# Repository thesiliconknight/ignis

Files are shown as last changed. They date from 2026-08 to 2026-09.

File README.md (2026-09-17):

# Ignis
A low-voltage controller board for driving a 220V 400W aluminum PTC heater via an external SSR, it has a NTC for temperature readings, an OLED status/info display, and MOSFET-isolated relay stuff. The board uses the CH32V006F8P6 MCU, its mainly used for triggering the SSR and reading temps,it keeps all mains voltage completely off of the board.
## Pictures
| Top View | Bottom View |
| :---: | :---: |
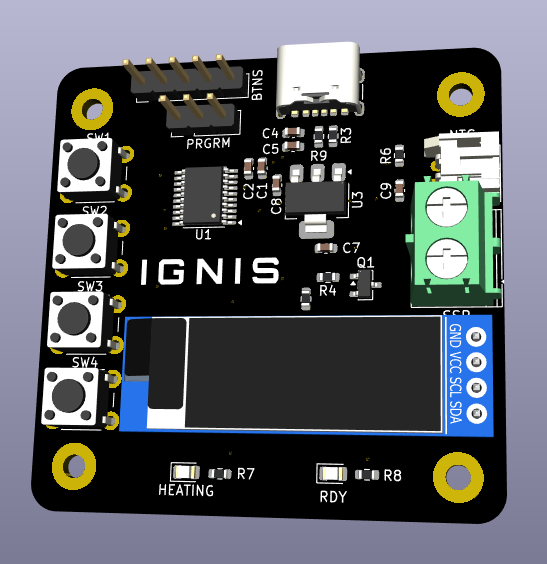
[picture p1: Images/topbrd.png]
Board Front
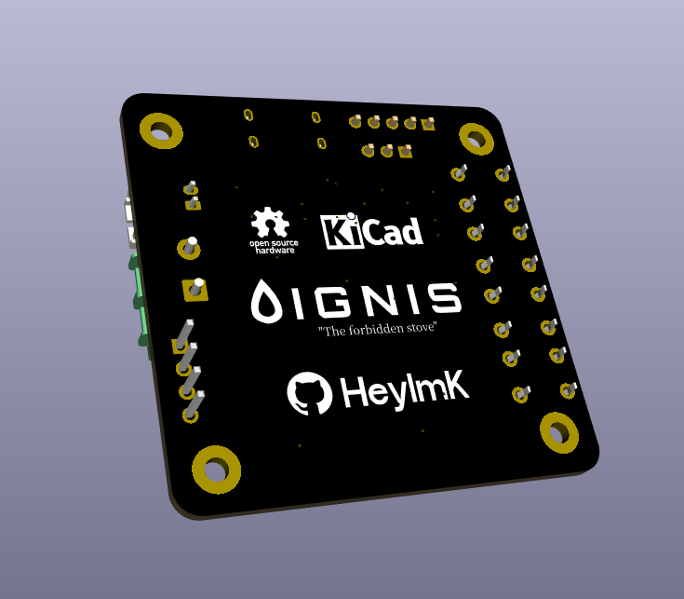
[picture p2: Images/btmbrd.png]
Board Back
|  |  |
## Features
* **Main Controller:** CH32V006F8P6,62KB Flash and 8KB RAM.
* **USB-C Power:** Board is powered over USB-C.
* **No High Voltage:** The PCB handles 5V/3.3V logic. The 220V AC mains load is kept off-board and switched safely via a external SSR.
* **Precision Sensing:** It uses a 100K NTC thermistor it can read up to 300°C.
* **OLED Interface:** I2C header for a 0.91" SSD1306 OLED displaying target temps, current temp, and heating status.
* **Status LEDs:** Inbuilt HEATING and RDY LEDs gives the heater state without needing a screen.
* **Button Header:** 5-pin header breaking out 4 tactile buttons for menu navigation.
## Components Used
* **Microcontroller:** WCH CH32V006F8P6 (TSSOP-20)
* **Power Input:** USB-C receptacle (power-only)
* **High Voltage Switch:** External SSR connected via terminal block
* **Heater:** 220V 400W PTC Aluminum Heating Plate
* **Thermistor:** 100K NTC connected via a JST-PH 2-pin connector
* **Screen:** 0.91" SSD1306 I2C OLED Module
* **Miscellaneous:** AMS1117-3.3V Regulator, AO3400A MOSFET, 4x tactile buttons, 2x status LEDs, and assorted 0603 passives.

## Bill of Materials (BOM)

| Qty | Component | Footprint | Designator(s) | Purchase Link | Price (Rs) |
| :---: | :--- | :--- | :--- | :--- | :--- |
| 1 | Conn_01x05_Socket (Buttons Header) | PinHeader_1x05_P2.54mm_Vertical | BTNS | N/A (any 2.54) | 0 (Already have) |
| 5 | 100nF Capacitor | C_0603_1608Metric | C1, C7, C8, C9, C4| [Link](https://www.google.com/aclk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) | 0 (Already have) |
| 1 | 1µF Capacitor | C_0603_1608Metric | C2 | [Link](https://robu.in/product/1uf-1000nf-50v-capacitor-0603-smd-package-pack-of-20/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) | 11.00 |
| 1 | 10µF Capacitor | C_0603_1608Metric | C5 | [Link](https://robu.in/product/cl10a106ma8nrnc-samsang-25v-10uf-x5r-%C2%B120-0603-multilayer-ceramic-capacitors-mlcc-smd-smt-rohs/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) | 20.00 |
| 2 | LED (Heating / Ready) | LED_0805_2012Metric | HEATING, RDY | N/A (any 0805) | 0 (Already have) |
| 1 | USB-C Receptacle (Power Only) | USB4125-xx-x 6P TopMnt Horizontal | J6 | [Link](https://www.ktron.in/product/6-pin-usb-type-c-connector-smd/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) | 15.00 |
| 1 | Conn_01x02_Socket (NTC) | JST_PH_S2B-PH-K_1x02_P2.00mm_Horizontal | NTC | [Link](https://robu.in/product/ph-aw-2mm-2-pin-wafer-male-connector-through-hole-right-angle/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) | 0 (Already have) |
| 1 | JST-PH 2.0 Female Connector | N/A (Off-board wire harness) | — | [Link](https://hubtronics.in/1508?srsltid=AU7gw4Wmjln1E9tSbj1yLX3e6CGLNVZjP4-da3Qo7EFz9MvRA4VvwUHm) | 5.00 |
| 1 | Conn_01x03_Pin (Programming Header) | PinHeader_1x03_P2.54mm_Vertical | PRGRM | N/A (any 2.54) | 0 (Already have) |
| 1 | AO3400A N-Channel MOSFET | SOT-23 | Q1 | [Link](https://robu.in/product/ao3400-xblw-30v-5-8a-34m%cf%894-5v5a-1-4w-700mv250ua-1-n-channel-sot-23-3l-mosfets-rohs/) | 18.00 |
| 2 | 5.1kΩ Resistor | R_0603_1608Metric | R3, R9 | [Link](https://www.etstore.in/products/g7551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) | 0 (Already have) |
| 1 | 1kΩ Resistor | R_0603_1608Metric | R4 | [Link](https://robu.in/product/1k-ohm-1-4w-0603-surface-mount-chip-resistor-pack-of-100/) | 10.15 |
| 1 | 10kΩ Resistor | R_0603_1608Metric | R5 | [Link](https://robu.in/product/10k-ohm-1-4w-0603-surface-mount-chip-resistor-pack-of-100/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) | 13.00 |
| 1 | 100kΩ Resistor | R_0603_1608Metric | R6 | [Link](https://robu.in/product/100k-ohm-1-4w-0603-surface-mount-chip-resistor-pack-of-100/) | 11.10 |
| 2 | 330Ω Resistor | R_0603_1608Metric | R7, R8 | [Link](https://robu.in/product/rc0603jr-07330rl-yageo-res-thick-film-0603-330-ohm-5-0-1w1-10w-%C2%B1100ppm-c-pad-smd-t-r/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) | 0 (Already have) |
| 1 | 0.91" I2C OLED | Untitled | SCREEN | [Link](https://www.ktron.in/product/0-91-inch-white-color-oled-display-i2c/) | 180.00 |
| 1 | Conn_01x02_Socket (SSR) | TerminalBlock_Phoenix_PT-1,5-2-5.0-H_1x02_P5.00mm_Horizontal | SSR | [Link](https://evelta.com/2-pin-screw-connectors-pcb/?sku=083-Prime-500-2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) | 18.00 |
| 4 | SW_Push (6mm Tactile) | SW_PUSH_6mm | SW1, SW2, SW3, SW4 | [Link](https://robu.in/product/tsd001b06035a03-bzcn-6mm-6mm-50ma-round-button-direct-insert-6mm-350gf-12v-plugin-tactile-switches-rohs/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) | 8.00 |
| 1 | CH32V006FxPx MCU | TSSOP-20_4.4x6.5mm_P0.65mm | U1 | [Link](https://www.etstore.in/products/a2668?_pos=1&_psq=ch32v006&_psid=08be7c9a0&_ss=e) | 40.00 |
| 1 | AMS1117-3.3 LDO | SOT-223-3_TabPin2 | U3 | [Link](https://robu.in/product/ams1117-3-3v-1a-sot-223-voltage-regulator-ic-pack-of-5-ics/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) | 18.00 |
| 1 | 220V 400W PTC Aluminum Heater Plate | N/A (Off-board) | — | [Link](https://hubtronics.in/aluminum-ptc-heating-plate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) | 500.00 |
| 1 | SSR-40 DA Solid State Relay | N/A (Off-board) | — | [Link](https://robu.in/product/dc-ac-ssr-40da-solid-state-relay-module-3-32vdc24-380vac-40a/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) | 269.00 |
| 1 | 100K NTC 3950 Thermistor | N/A (Off-board) | — | [Link](https://robu.in/product/thermistor-100k-ntc-1-meter-cable-temperature-sensor/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) | 42.00 |
| | | | | **Component Total:** | **1178.25 Rs** (12.30$)|

*Note: Shipping and delivery fees across various vendors will add an estimated 100 - 200 Rs to the final cost.*

| Schematic Design |
| :---: |
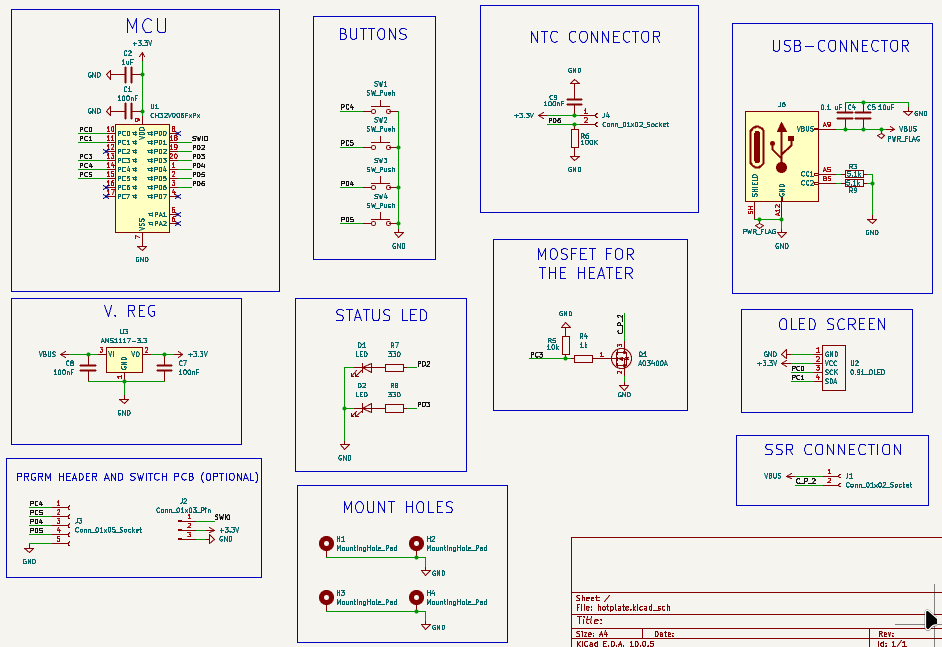
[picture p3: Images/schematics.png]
Schematic Diagram
|  |

| PCB Top Layer Routing | PCB Bottom Layer Routing |
| :---: | :---: |
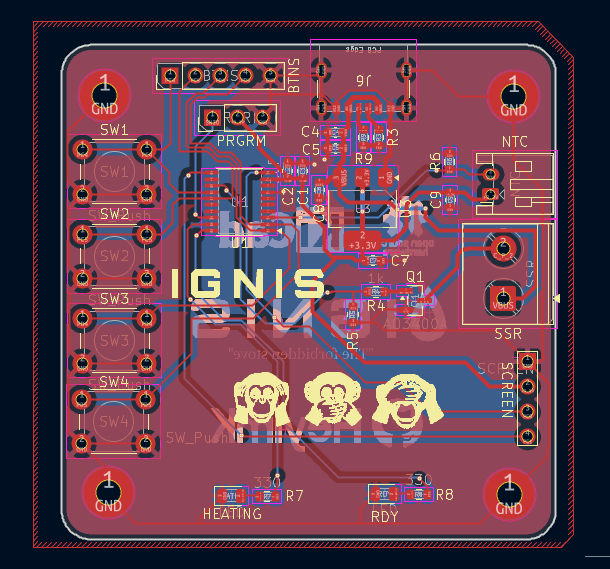
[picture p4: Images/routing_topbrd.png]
Top Routing
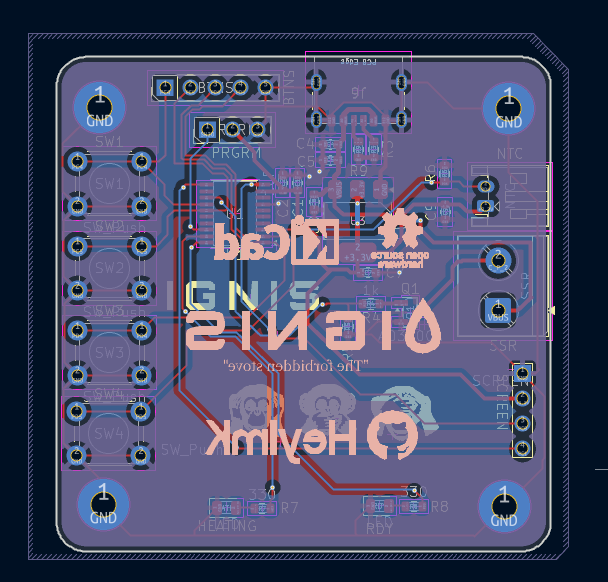
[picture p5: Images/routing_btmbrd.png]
Bottom Routing
|  |  |
### Connections
* **Power (USB-C to 3.3V):** 5V via USB-C (J6) and routes to the SSR connector and the AMS1117 V.REG (U3), which powers the MCU, OLED, and thermistor etc.
* **Thermistor Input (NTC):** Connects the 100K NTC between 3.3V and the MCU's ADC pin (PD2).
* **SSR Driver (SSR):** The MCU's PWM pin (PC3) switches the AO3400 Gate (Q1). The MOSFET pulls the negative side of the SSR terminal to GND, triggering the external relay.
* **OLED Header (SCREEN):** Connected to PC1 (SDA) and PC2 (SCK).
* **Button Header (BTNS):** 5-pin header breaking out the 4 tactile switches (SW1–SW4).
* **Programming Header (PRGRM):** Breaks out 3.3V, GND, and the single-wire debug line (PD1 / SWIO) for the programmer.
* **Status LEDs:** HEATING and RDY LEDs (Pin PD2 & PD3)
## License
This hardware project is open-source and licensed under the CERN Open Hardware Licence Version 2 - Strongly Reciprocal (CERN-OHL-S-2.0). 
You are free to copy, modify, distribute, and manufacture this board for personal or commercial use. However, if you modify these schematic or layout files and distribute your new design, you must release those modifications under this exact same CERN-OHL-S-2.0 license.
This design is shared without any warranty or implied guarantee. Check the LICENSE file for the full legal text.

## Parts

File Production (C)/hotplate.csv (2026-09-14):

Id | Designator | Footprint | Quantity | Designation | Supplier and ref
1 | BTNS | PinHeader_1x05_P2.54mm_Vertical | 1 | Conn_01x05_Socket
2 | C1, C7, C8, C9 | C_0603_1608Metric | 4 | 100nF
3 | C2 | C_0603_1608Metric | 1 | 1uF
4 | C4 | C_0603_1608Metric | 1 | 0.1 uF
5 | C5 | C_0603_1608Metric | 1 | 10uF
6 | HEATING, RDY | LED_0805_2012Metric | 2 | LED
7 | J6 | USB_C_Receptacle_GCT_USB4125-xx-x_6P_TopMnt_Horizontal | 1 | USB_C_Receptacle_PowerOnly_6P
8 | NTC | JST_PH_S2B-PH-K_1x02_P2.00mm_Horizontal | 1 | Conn_01x02_Socket
9 | PRGRM | PinHeader_1x03_P2.54mm_Vertical | 1 | Conn_01x03_Pin
10 | Q1 | SOT-23 | 1 | AO3400A
11 | R3, R9 | R_0603_1608Metric | 2 | 5.1k
12 | R4 | R_0603_1608Metric | 1 | 1k
13 | R5 | R_0603_1608Metric | 1 | 10k
14 | R6 | R_0603_1608Metric | 1 | 100K
15 | R7, R8 | R_0603_1608Metric | 2 | 330
16 | SCREEN | Untitled | 1 | 0.91_OLED
17 | SSR | TerminalBlock_Phoenix_PT-1,5-2-5.0-H_1x02_P5.00mm_Horizontal | 1 | Conn_01x02_Socket
18 | SW1, SW2, SW3, SW4 | SW_PUSH_6mm | 4 | SW_Push
19 | U1 | TSSOP-20_4.4x6.5mm_P0.65mm | 1 | CH32V006FxPx
20 | U3 | SOT-223-3_TabPin2 | 1 | AMS1117-3.3

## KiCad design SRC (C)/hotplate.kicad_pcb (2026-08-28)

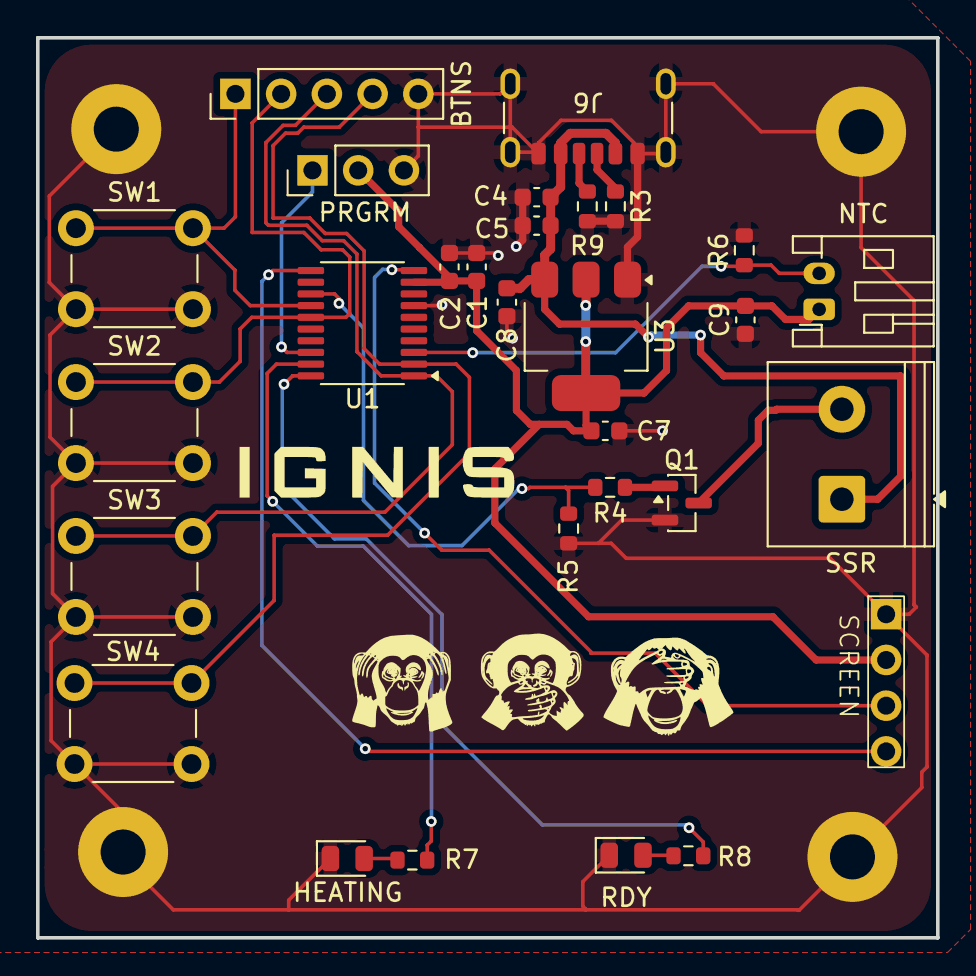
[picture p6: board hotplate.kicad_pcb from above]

Board: 2 copper layers, 50.0 x 50.0 mm, 33 parts (0 on the bottom side), 20 nets.

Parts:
BTNS: Conn_01x05_Socket; PinHeader_1x05_P2.54mm_Vertical
C1, C7, C8, C9: 100nF; C_0603_1608Metric
C2: 1uF; C_0603_1608Metric
C4: 0.1 uF; C_0603_1608Metric
C5: 10uF; C_0603_1608Metric
H1, H2, H3, H4: MountingHole_Pad; MountingHole_2.5mm_Pad
HEATING: LED; LED_0805_2012Metric
J6: USB_C_Receptacle_PowerOnly_6P; USB_C_Receptacle_GCT_USB4125-xx-x_6P_TopMnt_Horizontal
NTC: Conn_01x02_Socket; JST_PH_S2B-PH-K_1x02_P2.00mm_Horizontal
PRGRM: Conn_01x03_Pin; PinHeader_1x03_P2.54mm_Vertical
Q1: AO3400A; SOT-23
R3, R9: 5.1k; R_0603_1608Metric
R4: 1k; R_0603_1608Metric
R5: 10k; R_0603_1608Metric
R6: 100K; R_0603_1608Metric
R7, R8: 330; R_0603_1608Metric
RDY: LED; LED_0805_2012Metric
SCREEN: 0.91_OLED; Untitled
SSR: Conn_01x02_Socket; TerminalBlock_Phoenix_PT-1,5-2-5.0-H_1x02_P5.00mm_Horizontal
SW1, SW2, SW3, SW4: SW_Push; SW_PUSH_6mm
U1: CH32V006FxPx; TSSOP-20_4.4x6.5mm_P0.65mm
U3: AMS1117-3.3; SOT-223-3_TabPin2

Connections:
+3.3V: C1.2, C2.2, C7.1, C9.2, NTC.1, PRGRM.2, SCREEN.2 (VCC), U1.9 (VDD), U3.2 (VO)
/C_P_2: Q1.3 (D), SSR.2
/PC0: SCREEN.3 (SCK), U1.10 (PC0)
/PC1: SCREEN.4 (SDA), U1.11 (PC1)
/PC3: R4.2, R5.2, U1.13 (PC3)
/PC4: BTNS.1, SW1.1, U1.14 (PC4)
/PC5: BTNS.2, SW2.1, U1.15 (PC5)
/PD2: R7.1, U1.19 (PD2)
/PD3: R8.1, U1.20 (PD3)
/PD4: BTNS.3, SW3.1, U1.1 (PD4)
/PD5: BTNS.4, SW4.1, U1.2 (PD5)
/PD6: NTC.2, R6.1, U1.3 (PD6)
/SWIO: PRGRM.1, U1.18 (PD1)
GND: BTNS.5, C1.1, C2.1, C4.1, C5.1, C7.2, C8.2, C9.1, H1.1 (1_1), H2.1 (1_1), H3.1 (1_1), H4.1 (1_1), HEATING.1 (K), J6.A12 (GND), J6.B12 (GND), J6.SH (SHIELD), PRGRM.3, Q1.2 (S), R3.2, R5.1, R6.2, R9.2, RDY.1 (K), SCREEN.1 (GND), SW1.2, SW2.2, SW3.2, SW4.2, U1.7 (VSS), U3.1 (GND)
unnamed: HEATING.2 (A), R7.2
unnamed: R8.2, RDY.2 (A)
unnamed: J6.A5 (CC1), R3.1
unnamed: J6.B5 (CC2), R9.1
unnamed: Q1.1 (G), R4.1
VBUS: C4.2, C5.2, C8.1, J6.A9 (VBUS), J6.B9 (VBUS), SSR.1, U3.3 (VI)

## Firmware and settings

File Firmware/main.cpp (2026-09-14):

#include <Wire.h>
#include <Adafruit_GFX.h>
#include <Adafruit_SSD1306.h>

// pins
#define RELAY PC3  
#define NTC_PIN PD2
#define R_LED PA1
#define G_LED PA2
#define B_START PD4
#define B_UP PC5
#define B_DN PC4

float setpt = 220.0; 
float t_now = 0.0;
bool active = false; 
bool firing = false;

Adafruit_SSD1306 oled(128, 32, &Wire, -1);

void setup() {
  pinMode(RELAY, OUTPUT);
  pinMode(R_LED, OUTPUT);
  pinMode(G_LED, OUTPUT);
  
  // internal pullups for the tact switches
  pinMode(B_START, INPUT_PULLUP);
  pinMode(B_UP, INPUT_PULLUP);
  pinMode(B_DN, INPUT_PULLUP);
  
  digitalWrite(RELAY, LOW);
  digitalWrite(R_LED, LOW);
  digitalWrite(G_LED, LOW);

  Wire.begin();
  if(!oled.begin(SSD1306_SWITCHCAPVCC, 0x3C)) {
    while(true); // stuck here if screen is dead
  }
  
  oled.clearDisplay();
  oled.setTextSize(1);
  oled.setTextColor(SSD1306_WHITE);
  oled.setCursor(0, 10);
  oled.print("waking up...");
  oled.display();
  delay(1000);
}

void loop() {
  // hacky debounce lol
  if (!digitalRead(B_START)) {
    active = !active;
    delay(300); 
  }
  if (!digitalRead(B_UP)) {
    setpt += 5.0;
    delay(150);
  }
  if (!digitalRead(B_DN)) {
    setpt -= 5.0;
    delay(150);
  }

  int raw_adc = analogRead(NTC_PIN);
  
  // if thermistor unplugs it reads max/min usually
  if (raw_adc == 0 || raw_adc > 4090) {
    digitalWrite(RELAY, LOW);
    active = false;
    oled.clearDisplay();
    oled.setCursor(0,0);
    oled.print("ERR: SENSOR DED");
    oled.display();
    delay(500);
    return; 
  }

  // steinhart hart magic math
  float res = 100000.0 / ((4095.0 / (float)raw_adc) - 1.0);
  float kelvin = log(res / 100000.0);
  kelvin /= 3950.0;
  kelvin += 1.0 / (25.0 + 273.15);
  t_now = (1.0 / kelvin) - 273.15;

  // relay logic
  if (active) {
    if (t_now < (setpt - 2.0)) {
      digitalWrite(RELAY, HIGH);
      firing = true;
    } else if (t_now >= setpt) {
      digitalWrite(RELAY, LOW);
      firing = false;
    }
  } else {
    digitalWrite(RELAY, LOW);
    firing = false;
  }

  // blinkies
  if (active && firing) {
    digitalWrite(R_LED, HIGH);
    digitalWrite(G_LED, LOW);
  } else if (active && !firing) {
    digitalWrite(R_LED, LOW);
    digitalWrite(G_LED, HIGH);
  } else {
    digitalWrite(R_LED, LOW);
    digitalWrite(G_LED, LOW);
  }

  // draw screen stuff
  oled.clearDisplay();
  oled.setTextSize(1);
  oled.setCursor(0, 0);
  oled.print("Tgt:");
  oled.print(setpt, 0);
  
  oled.setCursor(80, 0);
  if(active) {
    oled.print(firing ? "HOT" : "OK");
  } else {
    oled.print("OFF");
  }

  oled.setTextSize(2);
  oled.setCursor(20, 15);
  oled.print(t_now, 1);
  oled.print("C");
  oled.display();
  
  delay(50); // don't freeze
}

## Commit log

2026-08-28 Revise README with detailed project specifications
    Updated project description, added features, components, BOM, connections, and license information.
2026-08-28 Update README with schematic and PCB routing images
2026-09-14 Add header row and format entries in hotplate.csv
    Updated the hotplate CSV file to include a header row and formatted the data entries.
    [hotplate.csv]
2026-09-17 bom w/ price test
2026-09-17 Revise BOM with updated components and costs
    Updated the Bill of Materials (BOM) section with new components and prices.
